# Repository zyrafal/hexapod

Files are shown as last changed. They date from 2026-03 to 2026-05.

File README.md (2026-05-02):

# 🤖 Hexadrone

A versatile, ROS 2 and ESP32 compatible software stack for a 18-DOF hexapod robot (drone). This repository contains the unified C++ brain, kinematics engine, Webots simulation environment, and the physical PlatformIO hardware layer.

📖 **For full hardware specifications, control mappings, architecture details, and system logic, please read the [Documentation](DOCUMENTATION.md).**

---

### 🛠️ Build Instructions
This ESP32 project relies on a shared core logic library. You must clone the entire ROS 2 workspace to maintain the correct folder structure:

1. Clone the complete workspace: `git clone yehorderehus/hexadrone`
2. Ensure `hexadrone_core` and `hexadrone_esp32` exist in the same parent directory.
3. Open the `hexadrone_esp32` folder in PlatformIO.
4. Click **Build**. PlatformIO will automatically resolve the symlink and download all external I2C/Radio libraries.

---

## 💻 Simulation Command Reference

Execute these from your host terminal to manage the containerized ROS 2 Jazzy environment using **Makefile**.

| Command | Action |
|---|---|
| **`make up`** | **Start** the Podman container in the background. |
| **`make build`**  | **Compile** C++ logic for `hexadrone_core` and `hexadrone_controller`. |
| **`make run`** | **Launch** Webots and ROS 2 nodes. Press **Ctrl+C** to exit. |
| **`make stop`** | **Kill** all container processes and stop the environment. |
| **`make shell`**  | **Enter** the interactive **fish** shell inside the container. |

---

## 🛠️ Debugging & Diagnostics (Shell Tab)
Use these commands inside `make shell` while the simulation is running to inspect the drone's state.

| Command | Purpose |
|---|---|
| `ros2 topic echo /joy` | Monitors raw input from the RadioMaster controller. |
| `ros2 topic echo /forward_position_controller/commands` | Monitors the 18 servo angles being sent to Webots. |
| `ros2 topic hz /joy` | Verifies that the teleop loop is running at the expected frequency. |
| `ros2 node info /teleop_node` | Shows which topics the Brain is currently reading and writing. |
| `ros2 param list` | Lists all active configuration parameters for the servos. |
| `ros2 doctor` | Runs a global diagnostic on the ROS 2 container environment. |

---

## 📡 Wireless Connection & OTA Updates

The Hexadrone features a state-aware WiFi manager designed to prioritize radio control safety. To prevent 2.4GHz interference with the ELRS receiver, **WiFi is strictly disabled while the drone is ARMED.** To connect to the drone wirelessly for diagnostics or code updates, you must be in the **DISARMED** or **OE-Kill** state.

### 1. Connecting to the Drone
1. **Configure your Network:** Ensure your local WiFi credentials (SSID and Password) are correctly set in `include/config.h`.
2. **Disarm the Drone:** Ensure your radio's ARM switch (Switch SA) is in the low/disarmed position. 
3. **Power On:** Boot the drone. The ESP32 will automatically connect to your designated WiFi network.
4. **Access the Network:** Make sure your PC or mobile device is connected to the same WiFi network. The drone will broadcast its presence via mDNS.

### 2. The Gunslinger Web Terminal
You do not need a USB cable to retrieve crash or walking data. While the drone is disarmed and connected to WiFi:
* Open any web browser on your connected device.
* Navigate to: `http://hexadrone.local/` (or use the direct IP address).
* You will be greeted by the **Maintenance Protocol** terminal. From here, you can download the `system.log`, retrieve the `power.csv` telemetry data, or wipe all internal logs from the LittleFS partition.

### 3. Over-The-Air (OTA) Firmware Updates
You can completely rewrite the ESP32's firmware wirelessly using PlatformIO's built-in ArduinoOTA support.
- To ensure maximum network stability and prevent hardware timeouts during Over-The-Air (OTA) updates, it is highly recommended to use the raw PlatformIO Command Line Interface (CLI) rather than the built-in VS Code "Upload" button.

```ini
~/.platformio/penv/bin/pio run -t upload
```

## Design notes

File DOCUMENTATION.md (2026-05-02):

# 🤖 M1A1-GUNSLINGER
> **System Class:** Tactical Hexadrone (V1.0)

## 🏗️ Project Architecture

The workspace is strictly divided to ensure the core mathematics remain perfectly portable between the high-level ROS 2 simulation and the low-level ESP32 microcontroller.

* **🧠 `hexadrone_core/` (The Brain)**
  * **Pure C++:** No ROS or ESP dependencies. Portable everywhere.
  * **`brain.cpp`**: Master coordinator, state machine, and real-time mixing.
  * **`kinematics.cpp`**: Forward Kinematics (FK) solver, dynamic body leaning, and servo safety clamping.
  * **`gait_engine.cpp`**: Generates elliptical walking paths, tripod balancing, and differential yaw.
* **🎮 `hexadrone_controller/` (The ROS 2 Wrapper)**
  * **`bridge_ops.hpp`**: Stateless translator converting `sensor_msgs/Joy` to normalized Core data.
  * **`teleop_node.cpp`**: Subscribes to `/joy`, ticks the Brain, and publishes to Webots.
* **🤖 `hexadrone_description/` (The Blueprint)**
  * Contains the `drone.urdf` (source of truth for dimensions), `.stl` visual meshes, and `ros2_control` configurations.
* **🌍 `hexadrone_webots/` (The Virtual Environment)**
  * Holds the Webots `hexaworld.wbt` testing ground, generated `.proto` nodes, and the ROS 2 `launch.py` scripts.
* **⚡ `hexadrone_esp32/` (The Physical Hardware)**
  * PlatformIO project that symlinks to `hexadrone_core`.
  * Manages ESP32 specifics: WiFi/OTA (`comms_manager`), CRSF decoding (`radio_manager`), PCA9685 PWM (`servo_manager`), INA228 Telemetry (`power_manager`), and Buffered File-System IO (`logger`).
* **📻 `Radiomaster/` (Transmitter Profiles)**
  * Contains the EdgeTX backup and configuration files specifically tuned for the RadioMaster Pocket. By copying these to the radio's SD card, you can instantly clone the exact control scheme without manual programming.
  * **`MODELS/`**: Houses the Hexadrone model profile. It pre-configures all 12 channels, including the custom logical switches for the trim-based Leg Selector and the EdgeTX telemetry alarms (e.g., haptic warnings for low voltage).
  * **`RADIO/`**: Contains the global radio settings, UI layout, and hardware calibrations required to map the physical layout of the Pocket to the Hexadrone's expected inputs.

## 🕹️ Control Mapping (RadioMaster Pocket / ELRS)

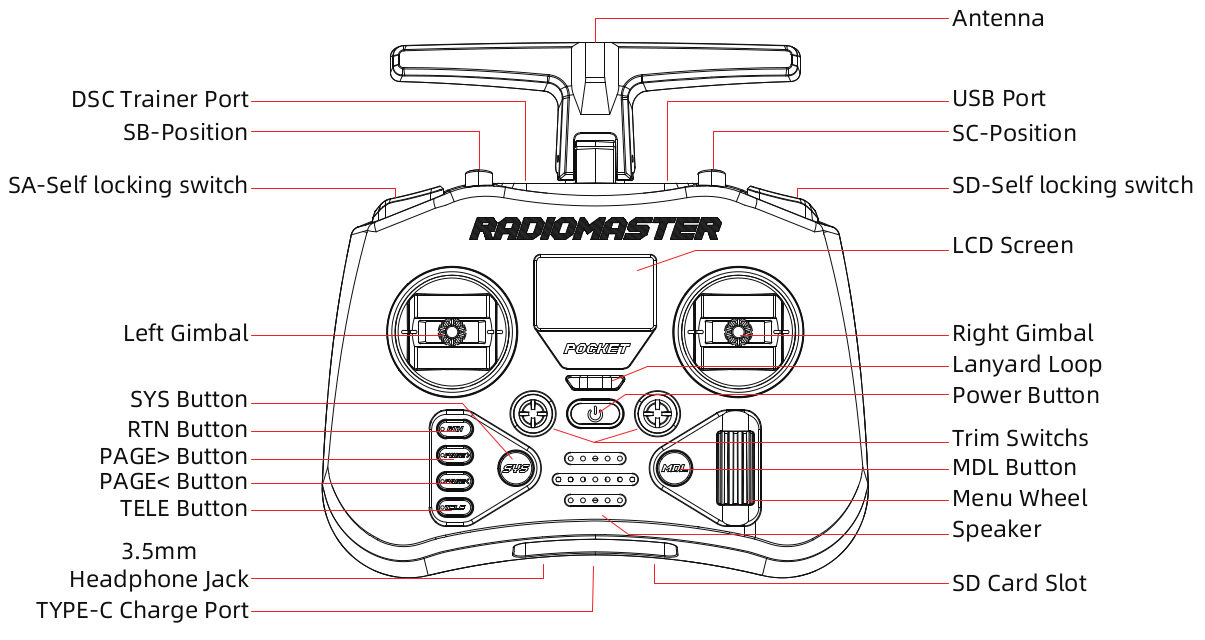
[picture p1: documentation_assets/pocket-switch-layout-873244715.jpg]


| Channel  | Input | Function | Logic / Behavior |
| :--- | :--- | :--- | :--- |
| **CH1**  | Right Stick (X) | **Body Roll** | Lean left/right |
| **CH2**  | Right Stick (Y) | **Body Pitch** | Lean forward/back |
| **CH3**  | Left Stick (Y)  | **Velocity (Gas)**  | Magnitude of the walking gait |
| **CH4**  | Left Stick (X)  | **Yaw (Turn)** | Rotation around the vertical Z-axis |
| **CH5**  | Switch SA | **ARM / Safety** | High: 1 (Armed) / Low: -1 (Disarmed) |
| **CH6**  | Switch SB | **Standing Height** | 3-Pos: Crouch (-1) / Std (0) / High (1)  |
| **CH7**  | Switch SC | **Transmission** | 3-Pos: Fwd (-1) / Neutral (0) / Bwd (1)  |
| **CH8**  | Left Trim (Y) | **Manual Tibia** | Extension reach for selected leg |
| **CH9**  | Button SE | **Kill-Switch** | Immediate Hard Software Cutoff |
| **CH10** | Left Trim (X) | **Leg Selector** | Cycle Legs 1-6 (Rising Edge Detect) |
| **CH11** | Right Trim (X)  | **Manual Coxa** | Horizontal swing for selected leg |
| **CH12** | Right Trim (Y)  | **Manual Femur** | Vertical lift for selected leg |

### ROS 2 /joy Topic Index Map in bridge_ops.hpp

| Index Type  | Index | Physical Control | Range / Logic (In C++) |
|---|---|---|---|
| **Axes** | `[0]` | Right Stick (X)  | -1.0 (Right) to 1.0 (Left) [Inverted] |
| **Axes** | `[1]` | Right Stick (Y)  | -1.0 (Down) to 1.0 (Up) [Inverted] |
| **Axes** | `[2]` | Left Stick (Y) | -1.0 (Down) to 1.0 (Up) [Inverted] |
| **Axes** | `[3]` | Left Stick (X) | -1.0 (Right) to 1.0 (Left) [Inverted] |
| **Axes** | `[4]` | Switch SB | -1.0 (Up) / 0.0 (Mid) / 1.0 (Down) [Inverted] |
| **Axes** | `[5]` | Knob S1 | -1.0 (Right) to 1.0 (Left) [Inverted] |
| **Buttons** | `[0]` | Switch SA | 0 (Low) / 1 (High) |
| **Buttons** | `[1]` | Button SE | 0 (Off) / 1 (On) |
| **Buttons** | `[2]` | Switch SD | 0 (Low) / 1 (High) |
| **Buttons** | `[3, 4]` | Right Trim (X) | 3: -1 (Left) / 4: 1 (Right) |
| **Buttons** | `[5, 6]` | Right Trim (Y) | 5: -1 (Down) / 6: 1 (Up) |
| **Buttons** | `[7, 8]` | Left Trim (Y) | 7: -1 (Down) / 8: 1 (Up) |
| **Buttons** | `[9, 10]`  | Left Trim (X) | 9: Prev Leg / 10: Next Leg |
| **Buttons** | `[11, 12]` | Switch SC | 11: Forward (-1) / 12: Backward (1) |

---

### ⚙️ System Logic

#### 1. ARM / DISARM Logic (Switch SA)
* **Armed State (Power On):**
    * **Initialization:** The system sequentially powers the leg motors with a 100ms delay to prevent electrical power spikes, positioning the drone in a prone position defined by the kinematic engine.
    * **Operational Posture:** Once all motors are active, the drone raises the chassis to the standing height set by Switch SB.
* **Disarm State (Power Off):** Initiates the **Soft Cutoff** sequence, safely lowering the drone before cutting power.
* **Radio Failsafe:** If the remote control signal is lost, the system automatically triggers the **Soft Cutoff** to ground the drone and wait for a reconnection.

#### 2. Manual Leg Control (CH11 - CH14)
* **Activation:** This mode is only available when the transmission (Switch SC) is in the Neutral position.
* **Leg Selection (CH14):** Use the trim switch to cycle through and select one of the 6 legs.
* **Joint Control:** Use the remaining trim switches to manually adjust the joints of the selected leg. This bypasses the automatic walking engine, making it useful for clearing mechanical jams or performing maintenance. Resets when changing the transmission.

#### 3. Emergency OE-Kill-Switch (Button SE)
* **Emergency Override:** A direct hardware interrupt designed to stop all movement instantly.
* **Execution:** Holding the button for **1 second** physically cuts the control signal to all motors.
* **Safety Lockout:** Once triggered, the system enters a permanent locked state. Pressing the EN (Reset) button on the ESP32 is sufficient to clear the state.
* **Context:** Reserved for critical emergencies like motor stalls, overheating, or loss of control.

#### 4. Soft Cutoff
* **Phase 1 (Lowering):** The kinematic engine commands the drone to take a prone posture.
* **Phase 2 (De-energizing):** Once in position, the system sequentially cuts power to the leg motors with a 100ms delay.
* **Purpose:** This two-step process prevents harmful electrical current spikes and protects the metal gears in the legs from the mechanical shock of a sudden drop.

## ⚡ Power System

### Power Diagram

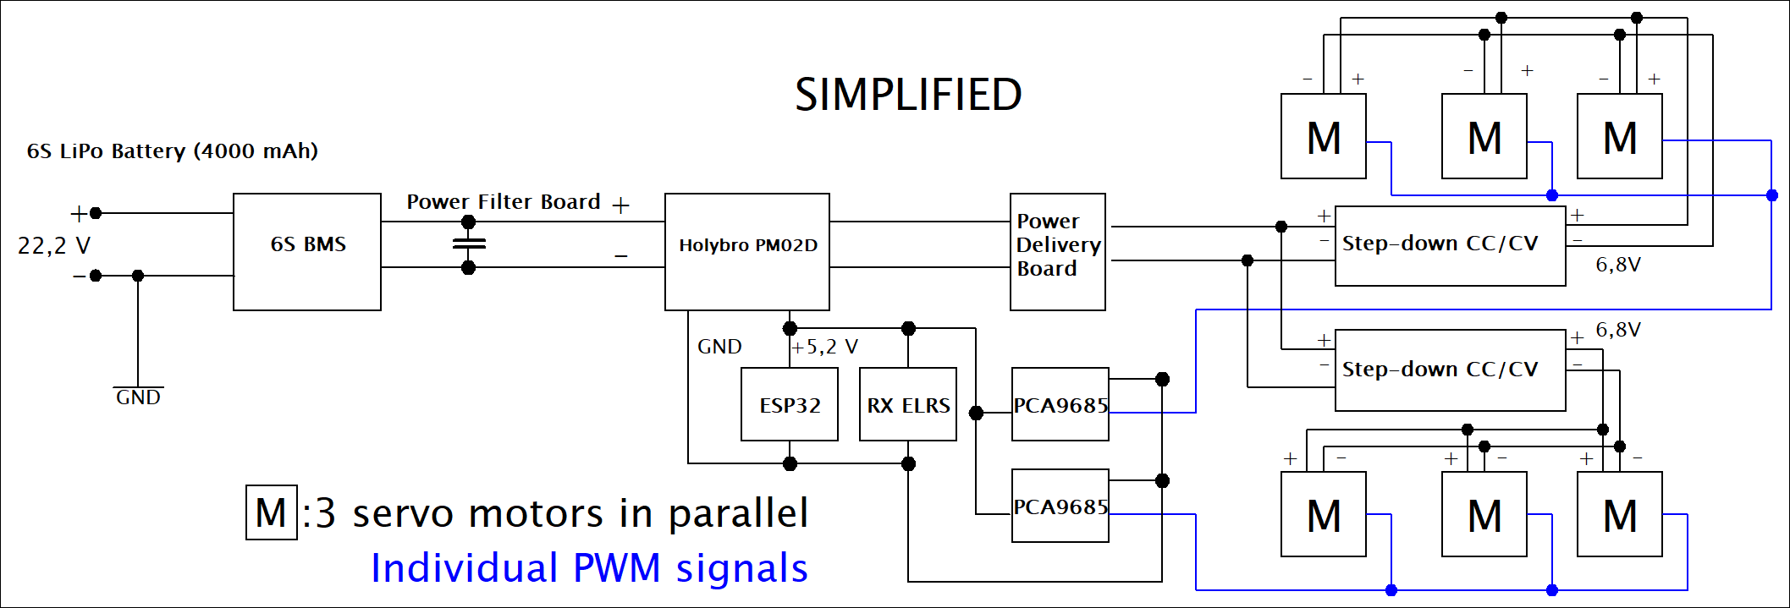
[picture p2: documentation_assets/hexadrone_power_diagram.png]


### Power Connectors (XT60 Flow)
1. **Battery** (Female) → **BMS** (Male - Soldered)
2. **BMS** (Female - Soldered) → **Power Module** (Male)
3. **Power Module** (Female) → **PDB** (Male - Soldered)

### Battery: 6S1P Partizan Li-ion
- **Capacity:** 4000 mAh (3200 mAh usable / 80%)
- **Energy Budget:** 71.04 Wh
- **Discharge:** 10C (Max 40A / 720W @ 18V)

### Charging Parameters (SkyRC S100neo)
- **Standard Charge:** Use **Balance CHG** mode set to **4.10V**. Set the charge current to **2.00A**.
- **Storage Mode:** If the drone is grounded for more than a few days, run the **Storage** mode to bring all cells to exactly **3.70V/c**. Leaving Li-ions fully charged degrades their capacity.

| Storage (3.80V/c) | Full Charge (4.10V/c) | Nominal (3.70V/c) | Minimum Safe (3.40V/c) | Dangerously Depleted (3.00V/c) |
|---|---|---|---|---|
| **22.80V** | **24.60V** | **22.20V** | **20.40V** | **18.00V** |

### Power Distribution

- **Logic:** 5.2V for ESP32, Servoshields, ELRS Receiver and other logic components
- **Servos Supply:** 6.8V via 2x Step-down converters
- **Efficiency:** 90% (Calculation factor: 1.1×)

## 🔋 Drone Estimated Runtime

| **Scenario** | **Mode Description** | **Current/Servo** | **Total Power** | **Runtime** | **HH:MM** |
|---|---|---|---|---|---|
| **Prone/Rest** | Electronics on, legs relaxed | 0.05A | 9.7W | 438 min | 07:18 |
| **Standing** | Holding 4kg (Quiescent) | 0.20A | 29.9W | 142 min | 02:22 |
| **Observed Avg** | Real mission profile | 0.36A | 51.5W | 83 min | 01:23 |
| **Active Gait**  | Smooth locomotion | 0.60A | 83.8W | 51 min | 00:51 |
| **Peak Burst** | Maximum dynamic effort | 1.00A | 137.6W | 31 min | 00:31 |
| **Extreme Load** | Continuous resistance | 1.20A | 164.6W | 26 min | 00:26 |

---

## 📊 Telemetry & System Monitoring

The Hexadrone utilizes a dual-layered telemetry system to ensure safety and real-time battery management. Data is aggregated by the ESP32 from the Holybro PM02D (I2C) and the Cyclone ELRS Receiver (UART).

### 1. On-Board OLED Status Display (128x32) (***Not yet implemented***)
A dedicated 0.91" OLED is mounted to the logic board for "at-a-glance" diagnostics during bench testing and field startup. The display is partitioned into four real-time data lines:

| Line | Display Example | Description (Data Source) |
|---|---|---|
| **1** | `23.2V \| 3.87V/c` | **Battery Potential:** Total voltage and calculated average per cell (6S). Primary indicator for "Fuel Pressure". |
| **2** | `6.2A \| 144.7W` | **System Load:** Instantaneous current draw and total power consumption. High values indicate mechanical resistance or stall. |
| **3** | `1250 mAh` | **Fuel Consumed:** Total capacity drained since power-on. Acts as the most accurate "Fuel Gauge" regardless of voltage sag. |
| **4** | `-45dBm \| 9:100` | **Link Health:** ELRS signal strength (RSSI) and Link Quality (LQ) for connection monitoring. |

### 2. RadioMaster Pocket (Remote Telemetry)
The **Cyclone ELRS Nano** receiver pushes a high-density telemetry stream to the RadioMaster Pocket. The primary telemetry screen (Screen 1) is configured as a **4x2 Nums** grid to monitor the "Gunslinger" mission status in real-time.

#### **Radiomaster Telemetry Layout**

| Position  | Left Column | Right Column |
|:---|:---|:---|
| **Row 1** | **`Vbat`**: Total Pack Voltage | **`V/c`**: Average Cell Voltage |
| **Row 2** | **`Watt`**: Total Power Consumption | **`mAh`**: Capacity Consumed |
| **Row 3** | **`TPWR`**: Transmitter Power | **`RSNR`**: Signal-to-Noise Ratio |
| **Row 4** | **`1RSS`**: Uplink Signal Strength  | **`RQly`**: Link Quality (Health) |

#### **Telemetry Thresholds & Diagnostics**

| Sensor | Unit | Good / Nominal | Warning / Bad | Description |
|---|---|---|---|---|
| **Vbat** | V | **22.2V – 24.6V**  | **< 21.0V** | Main battery voltage. Triggers **Soft Cutoff** landing sequence at 21.0V. |
| **V/c**  | V | **3.70V – 4.10V**  | **< 3.50V** | Average cell voltage ($Vbat / 6$). Essential for monitoring Li-ion health.  |
| **Watt** | W | **3.0W – 140.0W**  | **> 165.0W**  | Total system power. Spikes indicate mechanical stalls or "Extreme Load". |
| **mAh**  | mAh  | **0mAh – 3000mAh** | **> 3200mAh** | Total "fuel" gauge. Based on 80% usable capacity of the 4000mAh pack. |
| **TPWR** | mW | **10mW – 100mW** | **250mW** | Current TX output. 250mW indicates the radio is compensating for obstacles. |
| **RSNR** | dB | **> 5dB** | **< -15dB** | Signal cleanness. Lower values indicate high WiFi noise or interference. |
| **1RSS** | dBm  | **-30 to -80** | **< -105** | Raw uplink signal strength. -105dBm is the physical limit for the link. |
| **RQly** | % | **100%** | **< 80%** | **Critical Metric.** Percentage of packets successfully reaching the drone. |

### 3. Battery Management & Cutoff Logic
To ensure absolute safety, the battery management thresholds are implemented on **both** the ESP32 logic board (for physical execution) and the RadioMaster transmitter (for operator alerts). 

- **Cell Safety:** The Partizan Li-ion pack (10C rating) is capable of 40A continuous discharge. While the drone's average draw is lower (≈5–10A), the BMS is capable of handling 40A peaks.
- **Telemetry Monitoring:** The Holybro PM02D is used to feed real-time voltage data to the ESP32 via I2C.
- **Dual-Layer Logic:**
    - **Warning (< 21.0V | 3.5V/c for 2 seconds):** Triggers audio/haptic feedback on the RadioMaster Pocket. Logged by the ESP32.
    - **Soft Cutoff (< 20.4V | 3.4V/c for 5 seconds):** Forcibly intercepts the Radio controller's ARM switch on the ESP32 to trigger a graceful landing and alerts the operator.
    - **Immediate Hard Cutoff (< 18.0V | 3.0V/c):** Instantly triggers the Hardware OE-Kill gate on the ESP32 to prevent catastrophic battery damage and alerts the operator.
    - **Power Overload (> 165W for 0.5 seconds):** Triggers a unique haptic/audio warning on the RadioMaster to alert the operator of a mechanical jam or excessive weight load. (***TODO: Logged by the ESP32.***)
    - **USB Bench Mode (< 6.0V):** If the voltage reads below 6V, the system assumes it is being powered via USB (5V logic rail) without a battery attached. All cutoff logic is bypassed by the ESP32 to allow safe desktop debugging.

### 4. Wireless Debugging & Data Logging (Local Network)
The Hexadrone features a state-aware `CommsManager` and a dual-output `Logger` system designed to balance high-speed radio performance with robust diagnostic capabilities.

* **Radio-Priority WiFi:** To prevent 2.4GHz signal interference, WiFi is strictly suppressed while the drone is `ARMED`. The network stack only initializes upon entering a `DISARMED` state (or an Emergency `OE-KILL` state), allowing the drone to connect cleanly to the local network.
* **Buffered Blackbox Logging:** A dedicated `Logger` class (aliased as `Blackbox`) manages two separate data streams: `system.log` and `power.csv`.
* **The Gunslinger Web Terminal:** While `DISARMED`, operators can navigate to `http://hexadrone.local/` (***current bug: ESP32 IP has to be used***) to access the "Maintenance Protocol" UI. From this interface, you can instantly download the system logs, retrieve the power CSV, or wirelessly purge the internal flash storage.
* **Maintenance & OTA Updates:** The system supports wireless firmware deployment via Arduino OTA.

#### 5. ELRS Receiver "Auto-WiFi" State
To facilitate wireless firmware updates, the Cyclone ELRS receiver is programmed with an automatic timeout.
* **Behavior:** If the receiver does not establish a link with the RadioMaster Pocket within **60 seconds** of power-on, it enters **Auto-WiFi Mode**.
* **Visual Indicator:** The receiver LED will begin **blinking rapidly** (Double-blink pattern).
* **Lockout:** While in WiFi mode, the receiver's radio hardware is disabled. It will not respond to the controller until it is rebooted.
* **Resolution:** Power-cycle the drone with the RadioMaster Pocket already turned on, or adjust the `WiFi Auto On Interval` in the ELRS Lua script on the transmitter.

## 📈 Real-World Power Profiling

4kg Power Telemetry

To validate the theoretical endurance limits, the Gunslinger was tested in its heaviest 4 kg configuration. The telemetry data above illustrates the critical difference between continuous average draw and transient dynamic loads:

- **Quiescent Efficiency:** While standing still and actively holding the 4 kg mass, the current drops to approximately **0.20A per servo** (~30W total). This confirms that the resting posture effectively shifts the physical load through the mechanical frame rather than forcing the servos to constantly stall against gravity.
- **Mission Average:** During a standard continuous walking gait, the total system averages just **51.5W** (0.36A per servo). This high efficiency allows the servos to remain cool and yields an estimated continuous walking time of over **80 minutes**.
- **Dynamic Transients:** The sharp peaks reaching up to **140W** represent brief fractions of a second under extreme mechanical leverage—such as initiating a heavy step, overcoming momentum, or rapid directional changes.
- **Safety Integration:** These 140W spikes naturally cause momentary voltage sag across the 6S Li-ion battery.

### 🛠 Redundant Power Architecture & Thermal Management

- **Interleaved Fail-Safe Design:** The system utilizes two independent 300W step-down converters. Rather than a simple left/right split, the servos are organized in two interleaved groups to ensure static stability.
    - **Group A:** Left-Front (LF), Right-Middle (RM), Left-Back (LB)
    - **Group B:** Right-Front (RF), Left-Middle (LM), Right-Back (RB)
- **Redundancy Logic:** By powering opposing legs from different converters, the drone maintains a stable **tripod of active legs** even if one step-down unit shuts down. This prevents a catastrophic collapse and allows the drone to remain standing or perform a controlled emergency descent.
- **Current Overhead:** Each group of 9 servos pulls a peak stall current of 10.8A (@ 6.8V). Accounting for 90% converter efficiency, the input draw per converter is ≈11.88A.
    - *Safety Margin:* Operating at 11.88A stays well within the **15A recommended limit**, providing a 20% buffer. This "under-clocking" significantly reduces the risk of thermal shutdown compared to a single-converter setup.

## 📐 Detailed Wiring Schematic

[Hexadrone Detailed Schematic](documentation_assets/HEXADRONE_SCHEMATIC.svg)

This schematic details the exact pinouts, communication buses, and logic pathways for the Gunslinger:
* **Dual Power Rails:** Illustrates the physical split between the 5.2V logic rail (regulated by the Holybro PM02D) and the dual 6.8V high-current servo rails (driven by the 20A Buck Converters).
* **I2C Communication Bus:** Maps the shared SDA/SCL lines connecting the ESP32 to the power telemetry sensor and both PCA9685 servo drivers.
* **Hardware OE-Kill:** Shows the GPIO routing for the Output Enable (OE) pin, demonstrating how the ESP32 can physically cut the PWM signals to the servos during an emergency soft-cutoff or kill-switch event.
* **Actuator Mapping (Orientation Only):** This section provides the physical wiring guide for the 18 servos. Note that the schematic correctly illustrates the electrical grouping—**2 groups on address `0x40`** and **4 groups on address `0x41`**. 
    * **Note on Implementation:** This physical layout is for hardware orientation only. The functional joint assignments, pulse-width limits, and kinematic offsets are abstracted and further defined within the software architecture, specifically inside `config.h` and the `ServoManager` class.

### ⚙️ Hardware Components

- **Microcontroller (ESP32-WROOM):** The central brain of the hexadrone, featuring a convenient USB-C port for programming and a CH340 USB-to-Serial chip. It processes the core kinematics, state machine, WiFi/OTA networking, and I2C/UART data streams.
- **Radio Receiver (Cyclone ELRS 2.4G Nano):** Provides a robust, low-latency control link with a dedicated antenna. It pushes a continuous, high-density telemetry stream back to the operator.
- **Actuators (MG995 Metal Gear Servos):** Strong 180° digital servos equipped with durable metal gears. They are essential for handling the physical stress and momentum spikes of the drone's 4 kg weight.
- **Servo Drivers (PCA9685 16-Channel 12-bit PWM Mini Shield):** Offloads PWM signal generation from the ESP32 via I2C. These shields ensure precise, jitter-free angular control. Two modules are wired in parallel to handle all 18 joints.
- **Battery Management (SEQURE 40A 6S BMS):** A protection board tailored for the 6S pack. It balances cells and protects the system against over-current (up to 40A), over-charging, and deep discharging.
- **Telemetry Sensor (Holybro PM02D 12S HV Power Module):** Measures real-time voltage and current, feeding the data to the ESP32 via I2C. It also steps down the battery voltage to supply a clean 5.2V logic rail for the electronics.
- **Spike Suppression (Rush Blade Power Filter Board):** A TVS (Transient Voltage Suppressor) board that absorbs dangerous inductive voltage spikes ("back EMF") generated when 18 servos move and stop simultaneously, protecting the digital logic.
- **Power Converters (300W 20A CC/CV Step-Down):** High-power buck converters that step down the raw 6S battery voltage (20.4V - 24.6V) to a stable 6.8V for the servo motors.

## 🎛️ Configuration & Tuning (`config.h`)
To ensure maintainability, all critical tuning parameters are centralized in `config.h`. You do not need to modify the C++ manager classes to adjust drone behavior.
* **Battery:** Adjustable float thresholds for warnings, Soft, and Hard cutoffs, allowing quick swaps to different battery chemistries (e.g., standard LiPo vs. Li-ion).
* **Logging Limits:** Configurable RAM `BUFFER_SIZE` (default 1024 bytes) and `MAX_FLUSHES` (default 500) to safely balance flash-memory wear-leveling with mission duration. (***TODO: was changed, requires update***)
* **Timings:** Adjustments for the `SERVO_ARM_INTERVAL` (sequential motor wake-up speed) and `LOG_INTERVAL` (telemetry frequency).

## 📐 Mechanical Configuration

### Leg Dimensions

- **Coxa:** 68 mm
- **Femur:** 86.676 mm
- **Tibia:** 108.551 mm

#### Mounting Angles & Coordinates (from 0,0)

| **Leg ID** | **Location** | **dX (mm)** | **dY (mm)** | **Mounting Angle** |
|---|---|---|---|---|
| LM / RM | Middle | 120.250 | 0 | 90° |
| LF / RF | Front | 96.965 | 136.965 | 54.7° |
| LB / RB | Back | 96.965 | 136.965 | 54.7° |

- **Servo Limits:** −90° to +90° (Full 180° range)

## 🚀 Future Roadmap & Design Iterations (V2.0)

> While V1.0 focuses on structural validation and power stability, the next iteration aims for peak agility, weight efficiency, and advanced control.
> 

### 1. Structural Upgrades & Material Science

- **Carbon Fiber Integration:** Replace solid plastic sections with **Carbon Fiber Tubes**.
    - *Benefit:* Significant increase in the strength-to-weight ratio (WS). Carbon provides extreme rigidity with a fraction of the weight, reducing the inertia of the legs for faster gaits.
- **Filleting & Stress Distribution:** Implement aggressive edge filleting across all 3D-printed load-bearing parts.
    - *Benefit:* Reducing stress concentration points to prevent fatigue cracks and improving the overall aesthetic finish of the frame.

### 2. Mechanical Reconfiguration (Geometry V2)

- **Elevated Leg Pivot Points:** Redesign the chassis to mount leg attachment points (Coxa) higher than the bottom plate.
    - *Goal:* Increase **ground clearance** for traversing uneven terrain and lower the center of gravity (CoG) relative to the leg workspace.
- **Optimized Leg Placement (Ideal Hexa Angles):** Shift from current mounting angles to a more bio-inspired or kinematically optimal "Ideal Hexapod" configuration.
    - *Benefit:* Maximizing the overlap of leg workspaces, allowing for a 360° omnidirectional walk with fewer kinematic singularities.

### 3. Electronics & Control Paradigm Shift

- **Transition to Serial BUS Servos:** Replace the current PWM-based servos (controlled by PCA9685) with **Digital Serial BUS Servos** (e.g., STS/LX series).
    - **Wiring Efficiency:** Daisy-chain wiring (one cable through the whole leg) instead of 18 individual PWM lines. This drastically reduces the "spaghetti" effect in the chassis.
    - **Bi-directional Feedback:** Real-time monitoring of servo temperature, voltage, and exact position. This allows for *Active Compliance* (sensing when a leg hits an obstacle), not just using pressure sensors.
- **Construction Redesign:** A complete overhaul of the main body to accommodate the internal routing of BUS cables, electronics and battery compartment.

---

### 💡 Engineering Vision for V2.0

> **The ultimate goal** is to move from a "controlled walker" to an "autonomous scout." Elevating the legs and reducing mass with carbon fiber will allow the drone to handle outdoor environments (grass, gravel) where V1.0 might struggle due to low clearance.
>

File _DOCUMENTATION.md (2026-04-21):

## 🤖 Hexadrone
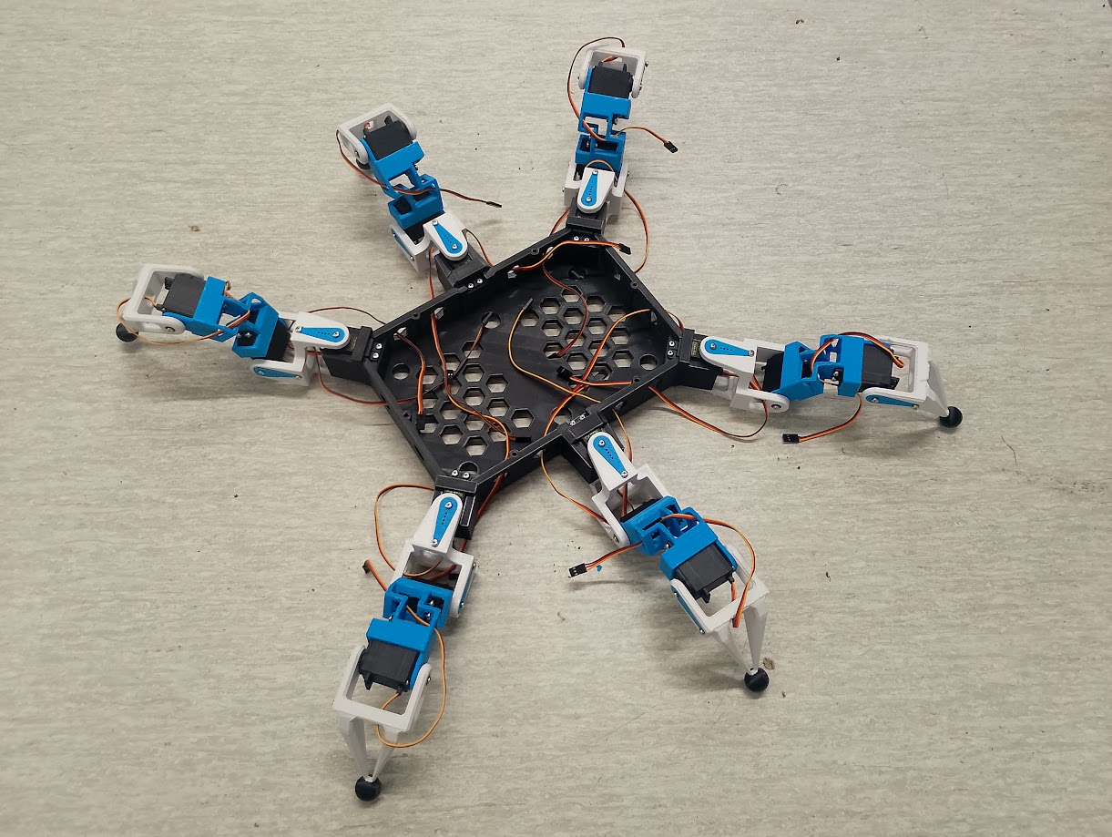
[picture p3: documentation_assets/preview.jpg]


## 🕹️ Control Mapping (RadioMaster Pocket / ELRS)



| Channel  | Radio Input | Function | Logic / Range |
|---|---|---|---|
| **CH1**  | Right Stick (X) | *Body Roll* | Additive lean left/right ***(Not yet implemented)*** |
| **CH2**  | Right Stick (Y) | *Body Pitch* | Additive lean forward/back ***(Not yet implemented*)** |
| **CH3**  | Left Stick (Y)  | **Velocity (Gas)**  | Movement speed (Magnitude of the gait) |
| **CH4**  | Left Stick (X)  | **Yaw (Turn)** | Rotation around the vertical Z-axis |
| **CH5**  | Switch SA | **ARM / Safety** | High: Armed / Low: Disarmed + Soft Cutoff |
| **CH6**  | Switch SD | *Auxiliary* | Unassigned (Future expansion) |
| **CH7**  | Switch SB | **Standing Height** | 3-Pos: -1:Crouching (Low) / 0:Standard / 1:High Stance |
| **CH8**  | Switch SC | **Transmission** | 3-Pos: -1:Forward / 0:Neutral (Manual) / 1:Backward |
| **CH9**  | Button SE | **Kill-Switch** | Immediate Hard cutoff (on condition, see below) |
| **CH10** | Knob S1 | *Auxiliary* | Unassigned (Future expansion) |
| **CH11** | Right Trim (X)  | **Manual Coxa** | Horizontal swing for selected leg |
| **CH12** | Right Trim (Y)  | **Manual Femur** | Vertical lift for selected leg |
| **CH13** | Left Trim (Y) | **Manual Tibia** | Extension/Reach for selected leg |
| **CH14** | Left Trim (X) | **Leg Selector** | Cycle through Legs 1-6 for individual control |

---

### ⚙️ System Logic

#### 1. ARM / DISARM Logic (Switch SA)
* **Armed State (Power On):**
    * **Initialization:** The system sequentially powers the leg motors with a 100ms delay to prevent electrical power spikes, positioning the robot in a prone position defined by the kinematic engine.
    * **Operational Posture:** Once all motors are active, the robot raises the chassis to the standing height set by Switch SB.
* **Disarm State (Power Off):** Initiates the **Soft Cutoff** sequence, safely lowering the robot before cutting power.
* **Radio Failsafe:** If the remote control signal is lost, the system automatically triggers the **Soft Cutoff** to ground the robot and wait for a reconnection.

#### 2. Manual Leg Control (CH11 - CH14)
* **Activation:** This mode is only available when the transmission (Switch SC) is in the Neutral position.
* **Leg Selection (CH14):** Use the trim switch to cycle through and select one of the 6 legs.
* **Joint Control:** Use the remaining trim switches to manually adjust the joints of the selected leg. This bypasses the automatic walking engine, making it useful for clearing mechanical jams or performing maintenance.

#### 3. Emergency Kill-Switch (Button SE)
* **Emergency Override:** A direct hardware interrupt designed to stop all movement instantly.
* **Execution:** Holding the button for **1 second** physically cuts the control signal to all motors.
* **Safety Lockout:** Once triggered, the system enters a permanent locked state. Pressing the EN (Reset) button on the ESP32 is sufficient to clear the state.
* **Context:** Reserved for critical emergencies like motor stalls, overheating, or loss of control.

#### 4. Soft Cutoff
* **Phase 1 (Lowering):** The kinematic engine commands the robot to take a prone posture.
* **Phase 2 (De-energizing):** Once in position, the system sequentially cuts power to the leg motors with a 100ms delay.
* **Purpose:** This two-step process prevents harmful electrical current spikes and protects the metal gears in the legs from the mechanical shock of a sudden drop.

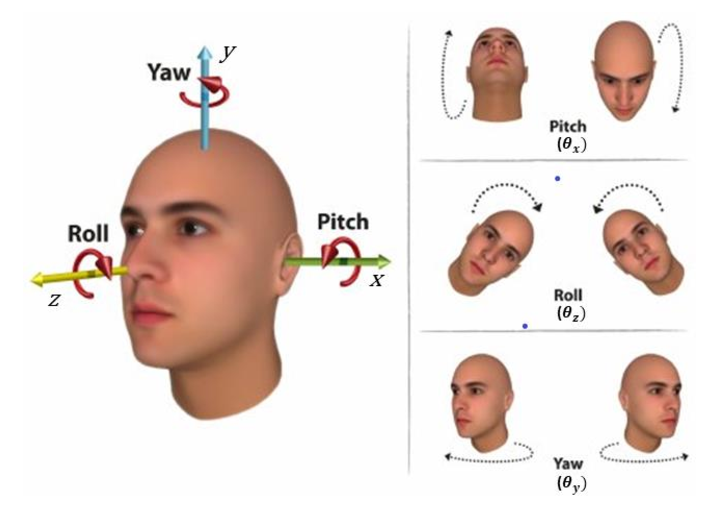
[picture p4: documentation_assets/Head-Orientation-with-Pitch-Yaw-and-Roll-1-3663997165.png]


## 📐 Mechanical Configuration

### Leg Dimensions

- **Coxa:** 68 mm
- **Femur:** 86.676 mm
- **Tibia:** 108.551 mm

#### Mounting Angles & Coordinates (from 0,0)

| **Leg ID** | **Location** | **dX (mm)** | **dY (mm)** | **Mounting Angle** |
|---|---|---|---|---|
| LM / RM | Middle | 120.250 | 0 | 90° |
| LF / RF | Front | 96.965 | 136.965 | 54.7° |
| LB / RB | Back | 96.965 | 136.965 | 54.7° |

- **Servo Limits:** −90° to +90° (Full 180° range)

## ⚡ Power System

### Power Diagram



### Battery: 6S1P Partizan Li-ion

- **Capacity:** 4000 mAh (3400 mAh usable / 85%)
- **Energy Budget:** 68 Wh
- **Discharge:** 10C (Max 40A / 720W @ 18V)

| Storage (3.80V/c) | Full Charge (4.10V/c) | Nominal (3.70V/c) | Minimum Safe (3.40V/c) | Dangerously Depleted (3.00V/c) |
|---|---|---|---|---|
| **22.80V** | **24.60V** | **22.20V** | **20.40V** | **18.00V** |

### Power Distribution

- **Logic:** 5.2V for ESP32, Servoshields, ELRS Receiver and other logic components
- **Servos Supply:** 6.8V via 2x Step-down converters
- **Efficiency:** 90% (Calculation factor: 1.1×)

## 🔋 Robot Estimated Runtime

| **Scenario** | **Mode Description** | **Total Power (W)** | **Runtime (Min)** | **Runtime (HH:MM)** |
| :--- | :--- | :--- | :--- | :--- |
| **Standing** | Holding weight (0.4A/servo) | 57.1W | 71 min | 01:11 |
| **Slow Walk** | Smooth gait (0.6A/servo) | 84.1W | 48 min | 00:48 |
| **Fast Walk** | Dynamic gait (0.8A/servo) | 111W | 36 min | 00:36 |
| **Dynamic Movements** | High activity (1.0A/servo) | 137.9W | 29 min | 00:29 |
| **Extreme Load**| Continuous resistance (1.2A/servo) | 164.9W | 24 min | 00:24 |

## 📊 Telemetry & System Monitoring

The Hexadrone utilizes a dual-layered telemetry system to ensure safety and real-time battery management. Data is aggregated by the ESP32 from the Holybro PM02D (I2C) and the Cyclone ELRS Receiver (UART).

### 1. On-Board OLED Status Display (128x32)
A dedicated 0.91" OLED is mounted to the logic board for "at-a-glance" diagnostics during bench testing and field startup. The display is partitioned into four real-time data lines:

| Line | Display Example | Description (Data Source) |
|---|---|---|
| **1** | `24.2V \| 4.0V/c` | **Battery Potential:** Total voltage and calculated average per cell (6S). Primary indicator for "Fuel Pressure". |
| **2** | `21.0A \| 144.7W` | **System Load:** Instantaneous current draw and total power consumption. High values indicate mechanical resistance or stall. |
| **3** | `1250 mAh` | **Fuel Consumed:** Total capacity drained since power-on. Acts as the most accurate "Fuel Gauge" regardless of voltage sag. |
| **4** | `-45dBm \| 9:100` | **Link Health:** ELRS signal strength (RSSI) and Link Quality (LQ) for connection monitoring. |

### 2. RadioMaster Pocket (Remote Telemetry)
The **Cyclone ELRS Nano** receiver utilizes a bidirectional link to push critical "Life-Support" data directly to the RadioMaster Pocket interface.

* **Link Health:** Real-time RSSI and Link Quality (LQ) are displayed on the radio's home screen to prevent out-of-range failures.
* **Battery Alarms:** The RadioMaster is configured to trigger haptic and voice alerts ("Battery Low") when the Holybro sensor reports a cell voltage below **3.5V (21.0V total)**.
* **Discovery:** All telemetry sensors (Vbat, Curr, RxBt) are discovered via the CRSF protocol, allowing for custom telemetry scripts (e.g., Yaapu) on the EdgeTX display.

### 3. Wireless Debugging & Data Logging (Local Network)
The Hexadrone features an internal `CommsManager` utilizing an ESP32 Async WebServer and LittleFS for untethered diagnostics. 

* **Background Network:** On boot, the robot connects non-blockingly to a designated WiFi hotspot (e.g., a mobile phone) and broadcasts its IP via mDNS (`http://hexadrone.local`).
* **Blackbox Logging:** `PowerManager` continuously writes telemetry (Voltage, Current, Watts, mAh, RSSI, and LQ) alongside internal `millis()` timestamps to the ESP32's flash memory. 
* **Remote Retrieval:** While the robot is active, the operator can navigate to `http://hexadrone.local/log` on any connected device to instantly download the `log.txt` file for analysis without plugging in a USB cable.
* **OTA Firmware:** Supports Arduino Over-The-Air (OTA) updates, allowing complete firmware rewrites wirelessly.

## 🛠 Engineering Notes & Safety

### 1. Redundant Power Architecture & Thermal Management

- **Interleaved Fail-Safe Design:** The system utilizes two independent 300W step-down converters. Rather than a simple left/right split, the servos are wired in two interleaved groups to ensure static stability.
    - **Group A:** Left-Front (LF), Right-Middle (RM), Left-Back (LB)
    - **Group B:** Right-Front (RF), Left-Middle (LM), Right-Back (RB)
- **Redundancy Logic:** By powering opposing legs from different converters, the robot maintains a stable **tripod of active legs** even if one step-down unit shuts down. This prevents a catastrophic collapse and allows the robot to remain standing or perform a controlled emergency descent.
- **Current Overhead:** Each group of 9 servos pulls a peak stall current of 10.8A (@ 6.8V). Accounting for 90% converter efficiency, the input draw per converter is ≈11.88A.
    - *Safety Margin:* Operating at 11.88A stays well within the **15A recommended limit**, providing a 20% buffer. This "under-clocking" significantly reduces the risk of thermal shutdown compared to a single-converter setup.

### 2. Electrical Protection Layers

- **Inductive Spike Suppression:** 18 servos moving simultaneously create significant "back EMF" (voltage spikes). The **Flywoo TVS Filter** must be installed at the PDB main input to protect the ESP32 and PCA9685 logic.
- **Decoupling Strategy:** Use Low ESR electrolytic capacitors (1000μF or higher) on both the 22.2V main rail and the 6.8V servo rails to prevent "brownouts" during high-torque bursts.
- **Common Ground:** Ensure all ground planes (Battery, PDB, ESP32, and Servo Drivers) are tied to a single point to prevent ground loops and I2C communication errors.

### 3. Battery Management & Cutoff Logic

- **Cell Safety:** The Partizan Li-ion pack (10C rating) is capable of 40A continuous discharge. While the robot's average draw is lower (≈5–10A), the BMS must be capable of handling 40A peaks.
- **Telemetry Monitoring:** Use the Holybro PM02D to feed real-time voltage data to the ESP32 via I2C.
- **Firmware Thresholds:**
    - **Warning (< 21.0V | 3.5V/c for 2 seconds):**
    - **Soft Cutoff (< 20.4V | 3.4V/c for 5 seconds)**
    - **Immediate Hard Cutoff (< 18.0V / 3.0V per cell**)

### 4. Geometry & Kinematics Constraints

- **Singularity Protection:** Mathematical limits in the Kinematics code must prevent the Coxa, Tibia and Femur from reaching collinearity, which could cause mechanical locking or servo over-torque.

## 🚀 Future Roadmap & Design Iterations (V2.0)

> While V1.0 focuses on structural validation and power stability, the next iteration aims for peak agility, weight efficiency, and advanced control.
> 

### 1. Structural Upgrades & Material Science

- **Carbon Fiber Integration:** Replace solid plastic sections with **Carbon Fiber Tubes**.
    - *Benefit:* Significant increase in the strength-to-weight ratio (WS). Carbon provides extreme rigidity with a fraction of the weight, reducing the inertia of the legs for faster gaits.
- **Filleting & Stress Distribution:** Implement aggressive edge filleting across all 3D-printed load-bearing parts.
    - *Benefit:* Reducing stress concentration points to prevent fatigue cracks and improving the overall aesthetic finish of the frame.

### 2. Mechanical Reconfiguration (Geometry V2)

- **Elevated Leg Pivot Points:** Redesign the chassis to mount leg attachment points (Coxa) higher than the bottom plate.
    - *Goal:* Increase **ground clearance** for traversing uneven terrain and lower the center of gravity (CoG) relative to the leg workspace.
- **Optimized Leg Placement (Ideal Hexa Angles):** Shift from current mounting angles to a more bio-inspired or kinematically optimal "Ideal Hexapod" configuration.
    - *Benefit:* Maximizing the overlap of leg workspaces, allowing for a 360° omnidirectional walk with fewer kinematic singularities.

### 3. Electronics & Control Paradigm Shift

- **Transition to Serial BUS Servos:** Replace the current PWM-based servos (controlled by PCA9685) with **Digital Serial BUS Servos** (e.g., STS/LX series).
    - **Wiring Efficiency:** Daisy-chain wiring (one cable through the whole leg) instead of 18 individual PWM lines. This drastically reduces the "spaghetti" effect in the chassis.
    - **Bi-directional Feedback:** Real-time monitoring of servo temperature, voltage, and exact position. This allows for *Active Compliance* (sensing when a leg hits an obstacle), not just using pressure sensors.
- **Construction Redesign:** A complete overhaul of the main body to accommodate the internal routing of BUS cables, electronics and battery compartment.

---

### 💡 Engineering Vision for V2.0

> **The ultimate goal** is to move from a "controlled walker" to an "autonomous scout." Elevating the legs and reducing mass with carbon fiber will allow the robot to handle outdoor environments (grass, gravel) where V1.0 might struggle due to low clearance.
>

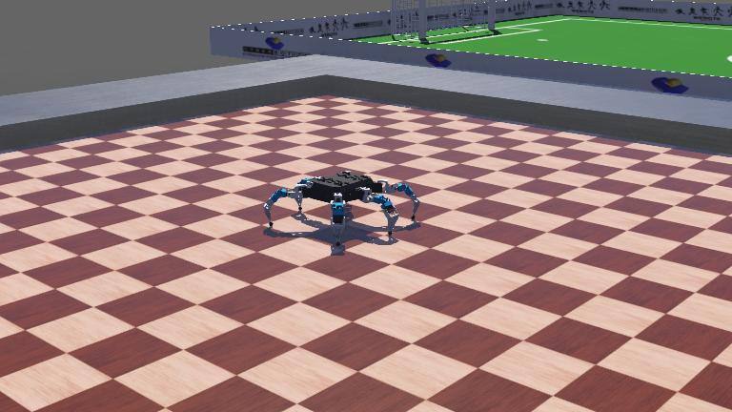
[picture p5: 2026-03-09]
src/hexadrone_webots/worlds/.hexaworld.jpg

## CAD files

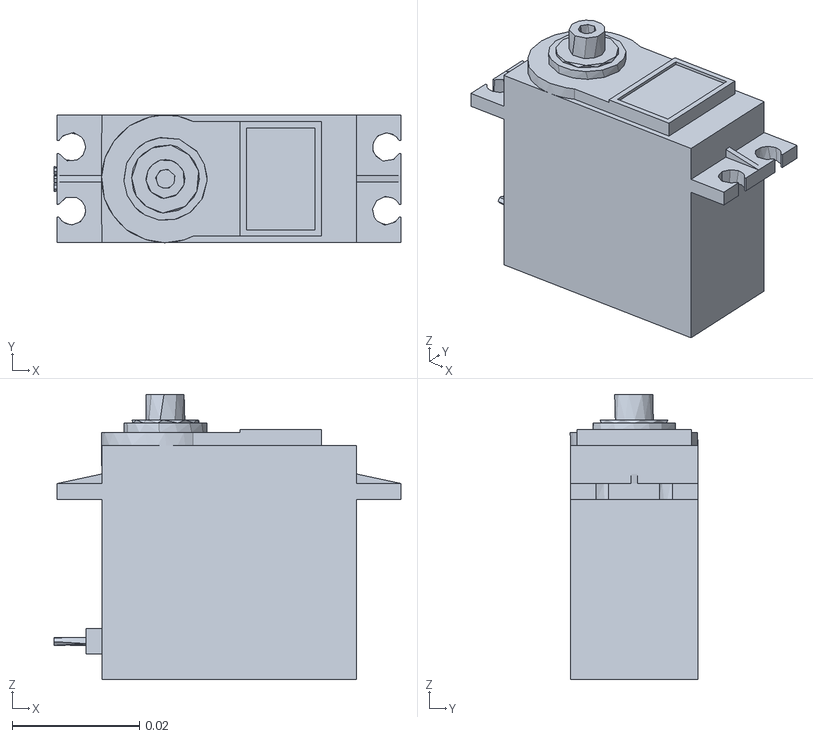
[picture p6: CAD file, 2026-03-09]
src/hexadrone_description/assets/rm_femur_servo.stl
0.0545 x 0.02 x 0.0448

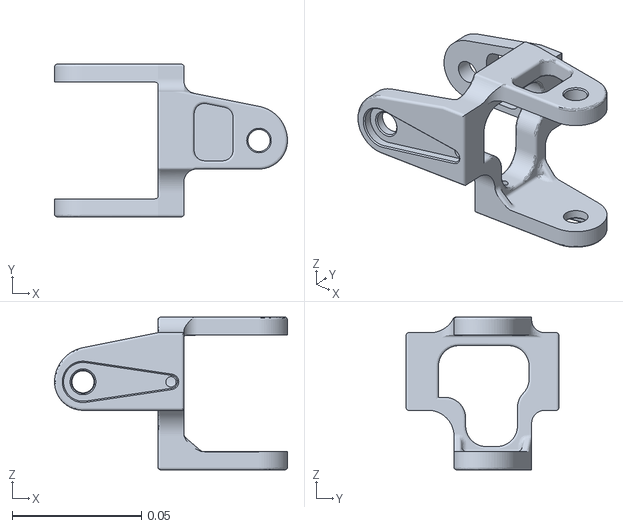
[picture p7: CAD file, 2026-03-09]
src/hexadrone_description/assets/lb_coxa.stl
0.09 x 0.059 x 0.059

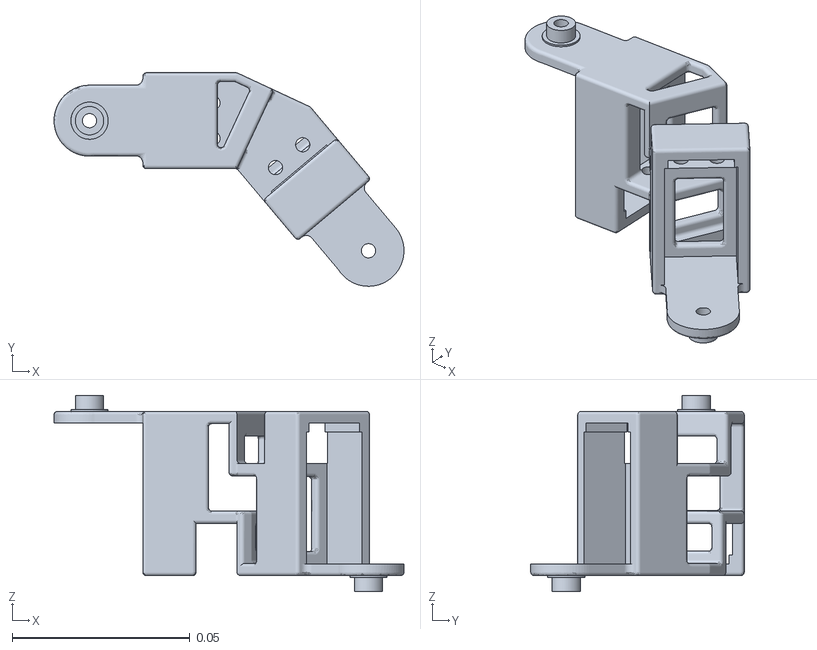
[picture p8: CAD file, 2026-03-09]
src/hexadrone_description/assets/rf_femur.stl
0.0985 x 0.0601 x 0.0553

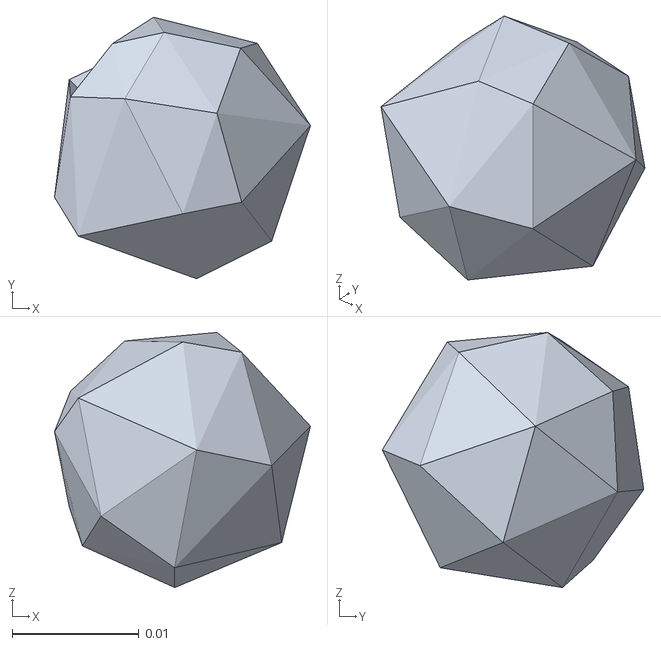
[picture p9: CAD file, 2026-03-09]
src/hexadrone_description/assets/rm_tip.stl
0.0202 x 0.0207 x 0.0202

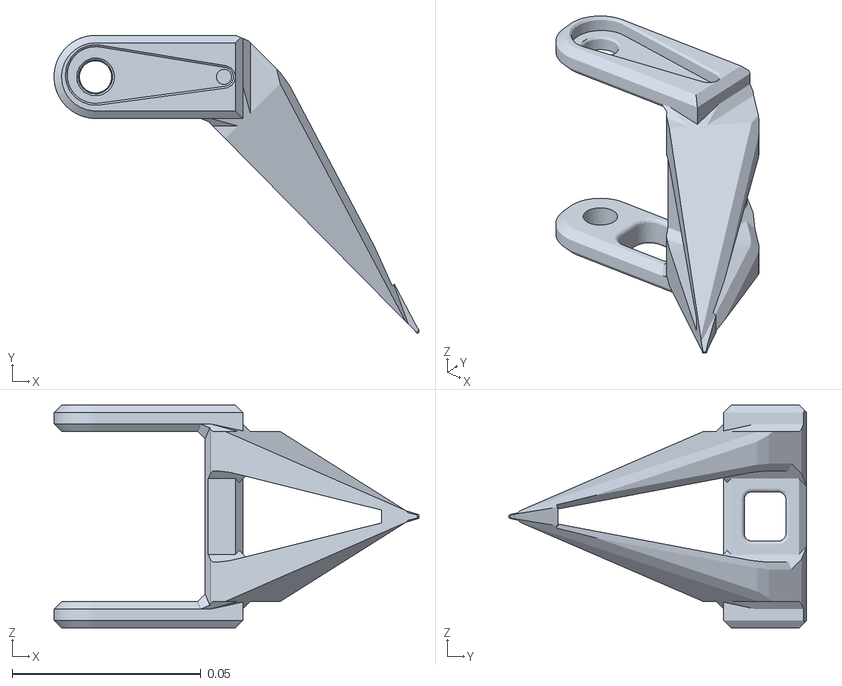
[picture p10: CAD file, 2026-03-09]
src/hexadrone_description/assets/rf_tibia.stl
0.0966 x 0.079 x 0.059

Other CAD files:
src/hexadrone_description/assets/lm_tibia_servo.stl
src/hexadrone_description/assets/rf_tibia_servo.stl
src/hexadrone_description/assets/lm_coxa.stl
src/hexadrone_description/assets/lf_femur.stl
src/hexadrone_description/assets/lm_coxa_servo.stl
src/hexadrone_description/assets/rb_coxa_servo.stl
src/hexadrone_description/assets/lb_femur.stl
src/hexadrone_description/assets/rf_tip.stl
src/hexadrone_description/assets/base_link.stl
src/hexadrone_description/assets/cover.stl
src/hexadrone_description/assets/lb_tibia.stl
src/hexadrone_description/assets/lf_tibia.stl
src/hexadrone_description/assets/lm_femur_servo.stl
src/hexadrone_description/assets/lm_tip.stl
src/hexadrone_description/assets/rb_coxa.stl
src/hexadrone_description/assets/rb_femur_servo.stl
src/hexadrone_description/assets/rb_tibia_servo.stl
src/hexadrone_description/assets/rb_tip.stl
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

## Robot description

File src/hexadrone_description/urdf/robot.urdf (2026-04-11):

<?xml version="1.0" ?>
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
<robot name="hexadrone_description">
  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
  <link name="base_link">
    <inertial>
      <origin xyz="-2.84e-10 6.073e-09 0.0317495" rpy="0 0 0"/>
      <mass value="1.57941"/>
      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
    </inertial>
    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
  </link>
  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
  <link name="lm_coxa">
    <inertial>
      <origin xyz="-0.0339313 0.000825246 -0.0290756" rpy="0 0 0"/>
      <mass value="0.0460937"/>
      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
    </inertial>
    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
  </link>
  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
  <link name="lm_femur_servo">
    <inertial>
      <origin xyz="0.0416637 0.0131447 -0.0249537" rpy="0 0 0"/>
      <mass value="0.143643"/>
      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
    </inertial>
    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
  </link>
  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
  <link name="lm_tibia">
    <inertial>
      <origin xyz="0.0409193 -0.0140246 -0.0257643" rpy="0 0 0"/>
      <mass value="0.0476647"/>
      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
    </inertial>
    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
  </link>
  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
  <joint name="LM_tibia" type="revolute">
    <origin xyz="0.0785173 0.0366132 -0.0496" rpy="3.14159 -0 0.872665"/>
    <parent link="lm_femur_servo"/>
    <child link="lm_tibia"/>
    <axis xyz="0 0 1"/>
    <limit effort="1.5" velocity="10" lower="-1.5708" upper="1.5708"/>
    <joint_properties friction="0.5"/>
  </joint>
  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
  <joint name="LM_femur" type="revolute">
    <origin xyz="-0.068 -0.0263 -0.0305" rpy="-1.5708 -0 -3.14159"/>
    <parent link="lm_coxa"/>
    <child link="lm_femur_servo"/>
    <axis xyz="0 0 1"/>
    <limit effort="1.5" velocity="10" lower="-1.5708" upper="1.5708"/>
    <joint_properties friction="0.5"/>
  </joint>
  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
  <joint name="LM_coxa" type="revolute">
    <origin xyz="0.12025 -0 0.0523" rpy="-0 -0 -3.14159"/>
    <parent link="base_link"/>
    <child link="lm_coxa"/>
    <axis xyz="0 0 1"/>
    <limit effort="1.5" velocity="10" lower="-1.5708" upper="1.5708"/>
    <joint_properties friction="0.5"/>
  </joint>
  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
  <link name="rm_coxa">
    <inertial>
      <origin xyz="-0.0339313 -0.000825297 -0.0290757" rpy="0 0 0"/>
      <mass value="0.0460939"/>
      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
    </inertial>
    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
  </link>
  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
  <link name="rm_tibia_servo">
    <inertial>
      <origin xyz="0.0416636 -0.0131447 -0.0249537" rpy="0 0 0"/>
      <mass value="0.143643"/>
      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
    </inertial>
    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
  </link>
  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
  <link name="rm_tip">
    <inertial>
      <origin xyz="0.0409193 0.0140246 -0.0257643" rpy="0 0 0"/>
      <mass value="0.0476648"/>
      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
    </inertial>
    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
  </link>
  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
  <joint name="RM_tibia" type="revolute">
    <origin xyz="0.0785173 -0.0366132 -0.0496" rpy="3.14159 0 -0.872665"/>
    <parent link="rm_tibia_servo"/>
    <child link="rm_tip"/>
    <axis xyz="0 0 1"/>
    <limit effort="1.5" velocity="10" lower="-1.5708" upper="1.5708"/>
    <joint_properties friction="0.5"/>
  </joint>
  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
  <joint name="RM_femur" type="revolute">
    <origin xyz="-0.068 0.0263 -0.0305" rpy="1.5708 0 -3.14159"/>
    <parent link="rm_coxa"/>
    <child link="rm_tibia_servo"/>
    <axis xyz="0 0 1"/>
    <limit effort="1.5" velocity="10" lower="-1.5708" upper="1.5708"/>
    <joint_properties friction="0.5"/>
  </joint>
  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
  <joint name="RM_coxa" type="revolute">
    <origin xyz="-0.12025 0 0.0523" rpy="0 0 0"/>
    <parent link="base_link"/>
    <child link="rm_coxa"/>
    <axis xyz="0 0 1"/>
    <limit effort="1.5" velocity="10" lower="-1.5708" upper="1.5708"/>
    <joint_properties friction="0.5"/>
  </joint>
  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
  <link name="rf_coxa">
    <inertial>
      <origin xyz="-0.0339313 0.000825246 -0.0290756" rpy="0 0 0"/>
      <mass value="0.0460937"/>
      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
    </inertial>
    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
  </link>
  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
  <link name="rf_femur">
    <inertial>
      <origin xyz="0.0416637 0.0131447 -0.0249537" rpy="0 0 0"/>
      <mass value="0.143643"/>
      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
    </inertial>
    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
  </link>
  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
  <link name="rf_tibia">
    <inertial>
      <origin xyz="0.0409193 -0.0140246 -0.0257643" rpy="0 0 0"/>
      <mass value="0.0476647"/>
      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
    </inertial>
    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
  </link>
  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
  <joint name="RF_tibia" type="revolute">
    <origin xyz="0.0785173 0.0366132 -0.0496" rpy="-3.14159 0 0.872665"/>
    <parent link="rf_femur"/>
    <child link="rf_tibia"/>
    <axis xyz="0 0 1"/>
    <limit effort="1.5" velocity="10" lower="-1.5708" upper="1.5708"/>
    <joint_properties friction="0.5"/>
  </joint>
  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
  <joint name="RF_femur" type="revolute">
    <origin xyz="-0.068 -0.0263 -0.0305" rpy="-1.5708 0 -3.14159"/>
    <parent link="rf_coxa"/>
    <child link="rf_femur"/>
    <axis xyz="0 0 1"/>
    <limit effort="1.5" velocity="10" lower="-1.5708" upper="1.5708"/>
    <joint_properties friction="0.5"/>
  </joint>
  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
  <joint name="RF_coxa" type="revolute">
    <origin xyz="-0.0969654 -0.136965 0.0523" rpy="0 0 0.785398"/>
    <parent link="base_link"/>
    <child link="rf_coxa"/>
    <axis xyz="0 0 1"/>
    <limit effort="1.5" velocity="10" lower="-1.5708" upper="1.5708"/>
    <joint_properties friction="0.5"/>
  </joint>
  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
  <link name="lf_coxa">
    <inertial>
      <origin xyz="-0.0339313 -0.000825297 -0.0290757" rpy="0 0 0"/>
      <mass value="0.0460939"/>
      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
    </inertial>
    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
  </link>
  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
  <link name="lf_tibia_servo">
    <inertial>
      <origin xyz="0.0416636 -0.0131447 -0.0249537" rpy="0 0 0"/>
      <mass value="0.143643"/>
      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
    </inertial>
    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
  </link>
  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
  <link name="lf_tibia">
    <inertial>
      <origin xyz="0.0409193 0.0140246 -0.0257643" rpy="0 0 0"/>
      <mass value="0.0476648"/>
      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
    </inertial>
    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
  </link>
  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
  <joint name="LF_tibia" type="revolute">
    <origin xyz="0.0785173 -0.0366132 -0.0496" rpy="3.14159 -0 -0.872665"/>
    <parent link="lf_tibia_servo"/>
    <child link="lf_tibia"/>
    <axis xyz="0 0 1"/>
    <limit effort="1.5" velocity="10" lower="-1.5708" upper="1.5708"/>
    <joint_properties friction="0.5"/>
  </joint>
  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
  <joint name="LF_femur" type="revolute">
    <origin xyz="-0.068 0.0263 -0.0305" rpy="1.5708 -0 3.14159"/>
    <parent link="lf_coxa"/>
    <child link="lf_tibia_servo"/>
    <axis xyz="0 0 1"/>
    <limit effort="1.5" velocity="10" lower="-1.5708" upper="1.5708"/>
    <joint_properties friction="0.5"/>
  </joint>
  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
  <joint name="LF_coxa" type="revolute">
    <origin xyz="0.0969654 -0.136965 0.0523" rpy="0 -0 2.35619"/>
    <parent link="base_link"/>
    <child link="lf_coxa"/>
    <axis xyz="0 0 1"/>
    <limit effort="1.5" velocity="10" lower="-1.5708" upper="1.5708"/>
    <joint_properties friction="0.5"/>
  </joint>
  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
  <link name="rb_coxa">
    <inertial>
      <origin xyz="-0.0339313 0.000825246 -0.0290756" rpy="0 0 0"/>
      <mass value="0.0460937"/>
      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
    </inertial>
    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
  </link>
  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
  <link name="rb_tibia_servo">
    <inertial>
      <origin xyz="0.0416637 0.0131447 -0.0249537" rpy="0 0 0"/>
      <mass value="0.143643"/>
      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
    </inertial>
    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
  </link>
  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
  <link name="rb_tibia">
    <inertial>
      <origin xyz="0.0409193 -0.0140246 -0.0257643" rpy="0 0 0"/>
      <mass value="0.0476647"/>
      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
    </inertial>
    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
  </link>
  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
  <joint name="RB_tibia" type="revolute">
    <origin xyz="0.0785173 0.0366132 -0.0496" rpy="3.14159 -0 0.872665"/>
    <parent link="rb_tibia_servo"/>
    <child link="rb_tibia"/>
    <axis xyz="0 0 1"/>
    <limit effort="1.5" velocity="10" lower="-1.5708" upper="1.5708"/>
    <joint_properties friction="0.5"/>
  </joint>
  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
  <joint name="RB_femur" type="revolute">
    <origin xyz="-0.068 -0.0263 -0.0305" rpy="-1.5708 0 3.14159"/>
    <parent link="rb_coxa"/>
    <child link="rb_tibia_servo"/>
    <axis xyz="0 0 1"/>
    <limit effort="1.5" velocity="10" lower="-1.5708" upper="1.5708"/>
    <joint_properties friction="0.5"/>
  </joint>
  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
  <joint name="RB_coxa" type="revolute">
    <origin xyz="-0.0969654 0.136965 0.0523" rpy="-0 0 -0.785398"/>
    <parent link="base_link"/>
    <child link="rb_coxa"/>
    <axis xyz="0 0 1"/>
    <limit effort="1.5" velocity="10" lower="-1.5708" upper="1.5708"/>
    <joint_properties friction="0.5"/>
  </joint>
  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
  <link name="lb_coxa">
    <inertial>
      <origin xyz="-0.0339313 -0.000825297 -0.0290757" rpy="0 0 0"/>
      <mass value="0.0460939"/>
      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
    </inertial>
    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
  </link>
  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

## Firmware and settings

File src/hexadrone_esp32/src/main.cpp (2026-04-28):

#include <Arduino.h>
#include <Wire.h>
#include <config.h>
#include <logger.h>
#include <comms_manager.h>
#include <power_manager.h>
#include <radio_manager.h>
#include <servo_manager.h>
#include <hexadrone_core/brain.hpp>

CommsManager comms;
PowerManager power;
RadioManager radio;
ServoManager servo;
Hexadrone::Brain brain;

// --- Timing ---

static unsigned long _lastLoopTime = 0;

static float getDt()
{
    unsigned long now = millis();
    float dt = (now - _lastLoopTime) / 1000.0f;
    _lastLoopTime = now;
    return dt;
}

// --- Setup / Loop ---

void setup()
{
    Serial.begin(DEBUG_BAUD);
    Serial.setTimeout(10); // Set to 10ms so it doesn't freeze the loop
    Wire.begin(SDA_CUSTOM, SCL_CUSTOM);
    Wire.setClock(400000); // 400kHz I2C speed
    Wire.setTimeOut(10);   // Set timeout to 10ms (default is much higher)

    Blackbox.begin();

    power.begin(); // INA228 has to be initialized first
    comms.begin(WIFI_SSID, WIFI_PASS);
    radio.begin();
    servo.begin();

    _lastLoopTime = millis();

    Blackbox.logSystem("[SYSTEM] Hexadrone Initialized.");
}

void loop()
{
    static Hexadrone::DroneState lastNormalState = Hexadrone::DroneState::DRONE_DISARMED;
    static bool radio_link_active = false;
    static bool arm_switch_released_since_link = false;
    static bool soft_cutoff_latched = false;
    static bool hard_cutoff_triggered = false;

    float dt = getDt();
    if (dt > 0.025f)
    { // If a loop takes longer than 25ms
        Blackbox.logSystem("[SYSTEM] Loop Time Spike detected: %.3f sec", dt);
    }

    bool otaLockdown = comms.isOTALockdown();
    if (otaLockdown)
    {
        // OTA mode: freeze legs, ignore radio, skip I2C sensors, keep WiFi alive
        Hexadrone::DroneState current_state = lastNormalState;
        comms.update(current_state);

        // Skip all other subsystems while OTA upload is in progress.
    }
    else
    {
        // 1. DATA ACQUISITION: Get the latest radio packets and timing
        radio.update();
        Hexadrone::ControllerInput input = radio.buildInput();

        // 2. FLY-BY-WIRE INTERCEPT: Radio connection and battery soft cutoff
        if (!radio.isConnected())
        {
            // If no radio link is present, always disarm the drone
            input.armed_switch = -1;
            radio_link_active = false;
            arm_switch_released_since_link = false;
        }
        else
        {
            // On first connect, require the ARM switch to be moved to DISARM before allowing ARMED state
            if (!radio_link_active)
            {
                radio_link_active = true;
                arm_switch_released_since_link = false;
            }

            if (input.armed_switch == -1)
            {
                arm_switch_released_since_link = true;
            }

            if (!arm_switch_released_since_link)
            {
                input.armed_switch = -1;
            }
        }

        if (soft_cutoff_latched)
        {
            // Force the Brain to think the physical switch is disarmed
            input.armed_switch = -1;
        }

        // 3. PROCESSING: Let the Brain decide the new state and angles
        std::vector<float> angles = brain.update(dt, input);
        Hexadrone::DroneState current_state = brain.getState();
        lastNormalState = current_state;

        // 4. BATTERY EVALUATION: Handle cuttoffs
        BatteryState batt_state = power.update(radio.getRSSI(), radio.getLQ());
        if (batt_state == BatteryState::HARD_CUTOFF && !hard_cutoff_triggered)
        {
            Blackbox.logSystem("[POWER] Hard Cutoff! Pulling power instantly.");
            hard_cutoff_triggered = true;
        }
        else if (batt_state == BatteryState::SOFT_CUTOFF && !soft_cutoff_latched)
        {
            Blackbox.logSystem("[POWER] Soft Cutoff! Forcing Disarm sequence.");
            soft_cutoff_latched = true;
        }

        // 5. SUBSYSTEM UPDATE: React to the new state
        comms.update(current_state);

        // 6. SAFETY GATE: Check the NEW state immediately
        if (current_state == Hexadrone::DroneState::DRONE_OE_KILLED || hard_cutoff_triggered)
        {
            servo.rapidKill();
        }
        else
        {
            // 7. ACTUATION: Send angles to hardware ONLY if safe and ARMED (or Prone)
            servo.update(current_state);

            // The gate now allows angles if ARMED *OR* if it is currently lowering to the ground
            // Set posture state for servo manager
            servo.setPostureState(brain.getPostureState());
            if (current_state == Hexadrone::DroneState::DRONE_ARMED || servo.isDisarming())
            {
                servo.applyAngles(angles);
            }
            else
            {
                // When fully disarmed and the timer has expired, this safely blocks
                // applyAngles so servo.update() can turn the chips off sequentially!
            }
        }
    }

    // 8. DEBUG COMMANDS
    if (Serial.available())
    {
        static String inputBuffer = ""; // Static keeps the memory alive between loops
        char c = Serial.read();

        // If it's a newline or carriage return, we are done typing
        if (c == '\n' || c == '\r')
        {
            if (inputBuffer.length() > 0)
            {
                inputBuffer.trim();

                if (inputBuffer == "xxwipelogxx")
                    Blackbox.wipeLog();
                else if (inputBuffer == "flush")
                {
                    Blackbox.flushSystem();
                    Blackbox.flushPower();
                }
                else if (inputBuffer == "dump")
                    Blackbox.dumpLog();

                inputBuffer = ""; // Clear the buffer for the next command
            }
        }
        else
        {
            // Add the letter to the buffer
            inputBuffer += c;
        }
    }
}

//
// In main.cpp loop()
// static unsigned long last_servo_update = 0;
// unsigned long now = millis();

// 1. Math is always updated for maximum precision
// std::vector<float> angles = brain.update(dt, input);

// 2. Physical hardware is updated only at the PWM frequency
// if (now - last_servo_update >= 20) { // 20ms = 50Hz
//    last_servo_update = now;
//    servo.applyAngles(angles);
//}

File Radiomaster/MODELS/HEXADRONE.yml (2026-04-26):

semver: 2.12.0
header:
  name: HEXADRONE
  bitmap: ""
  labels: ""
  modelId:
    0:
      val: 0
    1:
      val: 0
noGlobalFunctions: 0
thrTrim: 0
trimInc: 0
displayTrims: 2
ignoreSensorIds: 0
showInstanceIds: 0
disableThrottleWarning: 0
enableCustomThrottleWarning: 0
customThrottleWarningPosition: 0
beepANACenter: 0
extendedLimits: 1
extendedTrims: 0
throttleReversed: 0
checklistInteractive: 0
flightModeData:
  0:
    trim:
      0:
        value: 0
        mode: 18
      1:
        value: -2
        mode: 18
      2:
        value: 0
        mode: 18
      3:
        value: 0
        mode: 18
    name: ""
    fadeIn: 0
    fadeOut: 0
mixData:
  - destCh: 0
    srcRaw: I0
    weight: 100
    swtch: NONE
    curve:
      type: 0
      value: 0
    delayPrec: 0
    delayUp: 0
    delayDown: 0
    speedPrec: 0
    speedUp: 0
    speedDown: 0
    carryTrim: 0
    mltpx: ADD
    mixWarn: 0
    flightModes: 000000000
    offset: 0
    name: ""
  - destCh: 1
    srcRaw: I1
    weight: 100
    swtch: NONE
    curve:
      type: 0
      value: 0
    delayPrec: 0
    delayUp: 0
    delayDown: 0
    speedPrec: 0
    speedUp: 0
    speedDown: 0
    carryTrim: 0
    mltpx: ADD
    mixWarn: 0
    flightModes: 000000000
    offset: 0
    name: ""
  - destCh: 2
    srcRaw: I2
    weight: 100
    swtch: NONE
    curve:
      type: 0
      value: 0
    delayPrec: 0
    delayUp: 0
    delayDown: 0
    speedPrec: 0
    speedUp: 0
    speedDown: 0
    carryTrim: 0
    mltpx: ADD
    mixWarn: 0
    flightModes: 000000000
    offset: 0
    name: ""
  - destCh: 3
    srcRaw: I3
    weight: 100
    swtch: NONE
    curve:
      type: 0
      value: 0
    delayPrec: 0
    delayUp: 0
    delayDown: 0
    speedPrec: 0
    speedUp: 0
    speedDown: 0
    carryTrim: 0
    mltpx: ADD
    mixWarn: 0
    flightModes: 000000000
    offset: 0
    name: ""
  - destCh: 4
    srcRaw: SA
    weight: 100
    swtch: NONE
    curve:
      type: 0
      value: 0
    delayPrec: 0
    delayUp: 0
    delayDown: 0
    speedPrec: 0
    speedUp: 0
    speedDown: 0
    carryTrim: 0
    mltpx: ADD
    mixWarn: 0
    flightModes: 000000000
    offset: 0
    name: ""
  - destCh: 5
    srcRaw: SB
    weight: 100
    swtch: NONE
    curve:
      type: 0
      value: 0
    delayPrec: 0
    delayUp: 0
    delayDown: 0
    speedPrec: 0
    speedUp: 0
    speedDown: 0
    carryTrim: 0
    mltpx: ADD
    mixWarn: 0
    flightModes: 000000000
    offset: 0
    name: ""
  - destCh: 6
    srcRaw: SC
    weight: 100
    swtch: NONE
    curve:
      type: 0
      value: 0
    delayPrec: 0
    delayUp: 0
    delayDown: 0
    speedPrec: 0
    speedUp: 0
    speedDown: 0
    carryTrim: 0
    mltpx: ADD
    mixWarn: 0
    flightModes: 000000000
    offset: 0
    name: ""
  - destCh: 7
    srcRaw: SD
    weight: 100
    swtch: NONE
    curve:
      type: 0
      value: 0
    delayPrec: 0
    delayUp: 0
    delayDown: 0
    speedPrec: 0
    speedUp: 0
    speedDown: 0
    carryTrim: 0
    mltpx: ADD
    mixWarn: 0
    flightModes: 000000000
    offset: 0
    name: ""
  - destCh: 8
    srcRaw: SE
    weight: 100
    swtch: NONE
    curve:
      type: 0
      value: 0
    delayPrec: 0
    delayUp: 0
    delayDown: 0
    speedPrec: 0
    speedUp: 0
    speedDown: 0
    carryTrim: 0
    mltpx: ADD
    mixWarn: 0
    flightModes: 000000000
    offset: 0
    name: ""
  - destCh: 9
    srcRaw: P1
    weight: 100
    swtch: NONE
    curve:
      type: 0
      value: 0
    delayPrec: 0
    delayUp: 0
    delayDown: 0
    speedPrec: 0
    speedUp: 0
    speedDown: 0
    carryTrim: 0
    mltpx: ADD
    mixWarn: 0
    flightModes: 000000000
    offset: 0
    name: ""
  - destCh: 10
    srcRaw: T4
    weight: 100
    swtch: NONE
    curve:
      type: 0
      value: 0
    delayPrec: 0
    delayUp: 0
    delayDown: 0
    speedPrec: 0
    speedUp: 0
    speedDown: 0
    carryTrim: 0
    mltpx: ADD
    mixWarn: 0
    flightModes: 000000000
    offset: 0
    name: ""
  - destCh: 11
    srcRaw: T2
    weight: 100
    swtch: NONE
    curve:
      type: 0
      value: 0
    delayPrec: 0
    delayUp: 0
    delayDown: 0
    speedPrec: 0
    speedUp: 0
    speedDown: 0
    carryTrim: 0
    mltpx: ADD
    mixWarn: 0
    flightModes: 000000000
    offset: 0
    name: ""
  - destCh: 12
    srcRaw: T3
    weight: 100
    swtch: NONE
    curve:
      type: 0
      value: 0
    delayPrec: 0
    delayUp: 0
    delayDown: 0
    speedPrec: 0
    speedUp: 0
    speedDown: 0
    carryTrim: 0
    mltpx: ADD
    mixWarn: 0
    flightModes: 000000000
    offset: 0
    name: ""
  - destCh: 13
    srcRaw: T1
    weight: 100
    swtch: NONE
    curve:
      type: 0
      value: 0
    delayPrec: 0
    delayUp: 0
    delayDown: 0
    speedPrec: 0
    speedUp: 0
    speedDown: 0
    carryTrim: 0
    mltpx: ADD
    mixWarn: 0
    flightModes: 000000000
    offset: 0
    name: ""
limitData:
  0:
    min: 0
    max: 0
    revert: 0
    offset: 0
    ppmCenter: 0
    symetrical: 0
    name: ""
    curve: 32
  1:
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

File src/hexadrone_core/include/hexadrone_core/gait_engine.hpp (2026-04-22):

#ifndef HEXADRONE_GAIT_ENGINE_HPP
#define HEXADRONE_GAIT_ENGINE_HPP

#include "hexadrone_core/lib.hpp"
#include "hexadrone_core/state_machine.hpp"
#include <vector>

namespace Hexadrone
{
    class GaitEngine
    {
    public:
        GaitEngine();

        std::vector<float> update(float dt, float throttle, float yaw, GearState gear);

    private:
        float phase = 0.0f; // 0.0 to 1.0

        // Gait Tuning Constants
        static constexpr float STRIDE_LENGTH = 11.25f;  // Amplitude of Coxa swing
        static constexpr float LIFT_HEIGHT = 22.5f;    // Amplitude of Femur lift
        static constexpr float STEP_FREQUENCY = 2.5f; // Max speed of the gait cycle
        static constexpr float PHASE_OFFSET_B = 0.5f;  // Tripod timing (180 deg)
        static constexpr float INPUT_DEADZONE = 0.05f; // Stick drift protection
    };
}

#endif

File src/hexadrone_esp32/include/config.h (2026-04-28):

#pragma once

// WiFi Configuration
#define WIFI_SSID "norusko"
#define WIFI_PASS "azovsbs93"

// --- Hardware Mapping ---

// Maps Brain Logical Indices (0-5) to Physical Wiring Blocks (0-7)
//
// Logical: LF=0, RM=1, LB=2, RF=3, LM=4, RB=5
//
// Physical Blocks (4-pin spacing: 0, 4, 8, 12):
// Board 1 (0x40): Block 0 (Pins 0-2), Block 1 (Pins 4-6), Block 2 (Pins 8-10), Block 3 (Pins 12-14)
// Board 2 (0x41): Block 4 (Pins 0-2), Block 5 (Pins 4-6), Block 6 (Pins 8-10), Block 7 (Pins 12-14)

constexpr int LOGICAL_TO_PHYSICAL[6] = {
    1, // Logical 0 (LF) -> Board 1 (0x40), Pins 4-6   (Block 1)
    0, // Logical 1 (RM) -> Board 1 (0x40), Pins 0-2   (Block 0)
    4, // Logical 2 (LB) -> Board 2 (0x41), Pins 0-2   (Block 4)
    5, // Logical 3 (RF) -> Board 2 (0x41), Pins 4-6   (Block 5)
    6, // Logical 4 (LM) -> Board 2 (0x41), Pins 8-10  (Block 6)
    7  // Logical 5 (RB) -> Board 2 (0x41), Pins 12-14 (Block 7)
};

// --- Servo Direction Calibration ---
// 1.0f = Normal, -1.0f = Inverted
// Order: [Coxa, Femur, Tibia] for each leg (0-5)
constexpr float SERVO_SIGNS[18] = {
    // Group A (LF, RM, LB) - Swapped to POSITIVE
    1.0f, -1.0f, 1.0f, // Leg 0 (LF)
    1.0f, -1.0f, 1.0f, // Leg 1 (RM)
    1.0f, -1.0f, 1.0f, // Leg 2 (LB)

    // Group B (RF, LM, RB) - Swapped to NEGATIVE
    -1.0f, 1.0f, -1.0f, // Leg 3 (RF)
    -1.0f, 1.0f, -1.0f, // Leg 4 (LM)
    -1.0f, 1.0f, -1.0f  // Leg 5 (RB)
};

// I2C Pins
#define SDA_CUSTOM 25
#define SCL_CUSTOM 33
#define OE_CUSTOM 23

// Radio Pins
#define CRSF_RX_PIN 27
#define CRSF_TX_PIN 26

// I2C Addresses
#define ADDR_SERVO_1 0x40
#define ADDR_SERVO_2 0x41
#define ADDR_POWER 0x45

// --- Software mapping ---

// Logging & Blackbox Configuration
#define BLACKBOX_BUFFER_SIZE 1024 // RAM buffer before flushing (bytes)
#define BLACKBOX_MAX_FLUSHES 500
#define LOG_VOLTAGE_THRESH 0.2f
#define LOG_CURRENT_THRESH 0.5f

// Battery voltages (V) and intervals (ms)
#define HARD_CUTOFF_VOLTAGE 18.0f // 3.0V per cell
#define SOFT_CUTOFF_VOLTAGE 20.4f // 3.4V per cell
#define SOFT_CUTOFF_INTERVAL 5000
#define WARNING_VOLTAGE 21.0f // 3.5V per cell
#define WARNING_INTERVAL 2000

// Arming Intervals (ms)
#define SERVO_ARM_INTERVAL 100
#define DISARM_TRIGGER_INTERVAL 2000

// Baud rates
#define DEBUG_BAUD 115200
#define RADIO_BAUD 420000

// Servo PWM Ticks (Standard 0.5ms - 2.5ms range)
#define PWM_FREQ 50
#define SERVOMIN 105 // Usually the 0 degree limit
#define SERVOMAX 515 // Usually the 180 degree limit

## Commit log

2026-04-03 ESP32 logic WIP
2026-04-03 Structure updated, bugs fixed, ESP should work with basic functions
    [lib.hpp, main.cpp]
2026-04-09 Clean up and polish some files, structure
    [base_link.stl, cover.stl, lb_coxa.stl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]
2026-04-10 Started ROS2 implementation
    [ros2_control.yaml]
2026-04-11 Add keyboard control in Webots simulation
    [robot.urdf]
2026-04-13 Fix movement, implement ESP32
    [ros2_control.yaml]
2026-04-21 Proceeding with fixes (currently messed up)
    [ros2_control.yaml]
2026-04-23 ESP32 package nearly completed, yet without testing
2026-04-26 Increase the simulation weight to 5kg to match the expected real
2026-04-26 Logging updraged, OTA fixed, telemetry improved, ready for physical debug
    [config.h, main.cpp]
2026-04-27 Hotfix - working, systems and logging without issues, walking and roll&pitch with problems; chaotic fixes and inconsistent comments
    [config.h, main.cpp]
2026-04-28 Interim fix, crsf telemetry implemented
    [config.h, main.cpp]
2026-05-02 Update docs
    [power_27_04.csv]
